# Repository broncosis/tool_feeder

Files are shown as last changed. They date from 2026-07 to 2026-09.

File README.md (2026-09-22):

# Tool Feeder

> **⚠ Experimental.** Under active development and tested on a limited set of
> hardware. Expect rough edges. Review generated configs before use and keep
> an eye on your printer — use at your own risk.

Filament management for Klipper toolchangers — automated per-tool loading,
live filament-lane status on the touchscreen, and Spoolman integration. Pick
any combination of:

- **Filament Feeder** — automated per-tool filament loading (macros + a buffer
  sync module supporting both one- and two-sensor hardware)
- **Spoolman Lane Sync** — background service that syncs Spoolman spool data into
  Moonraker's `lane_data` so OrcaSlicer sees what's loaded in each tool slot
- **KlipperScreen Filament Lanes** — a touchscreen panel showing live filament-lane
  status per tool

Each component installs independently.

## Screenshots

| Filament Lanes | Tool Map |
| --- | --- |
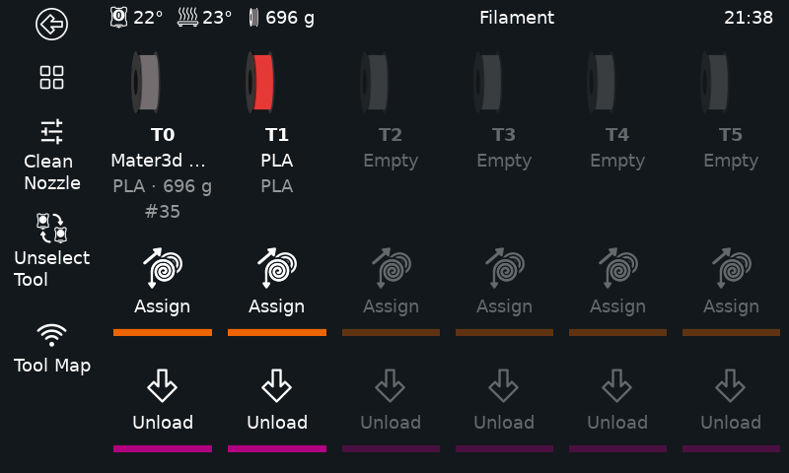
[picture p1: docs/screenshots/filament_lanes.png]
Filament Lanes
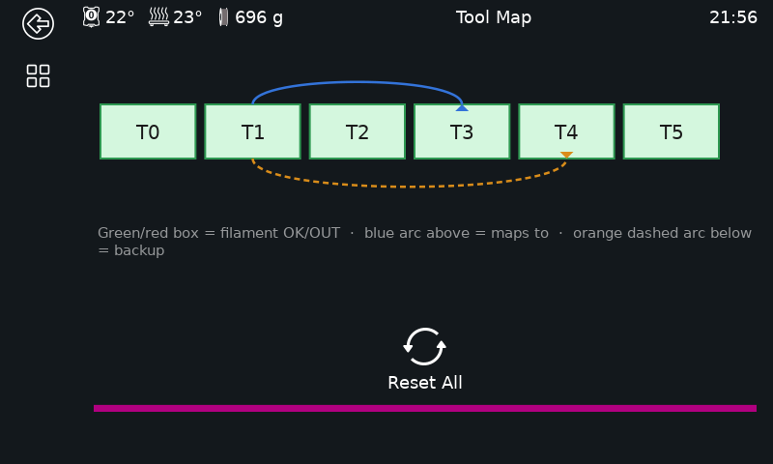
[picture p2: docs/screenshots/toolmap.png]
Tool Map
|  |  |
| Live per-lane status, right from the sidebar | Every tool's mapping at a glance |

| Manual Assign | Spoolman Assign |
| --- | --- |
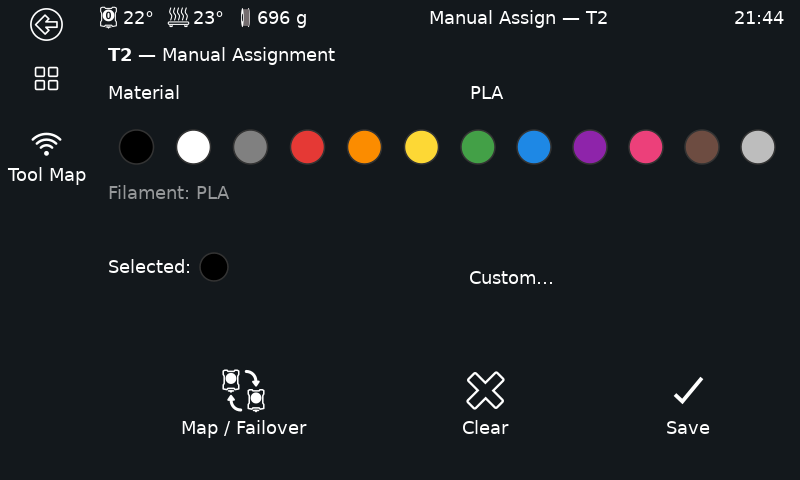
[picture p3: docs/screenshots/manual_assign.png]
Manual Assign
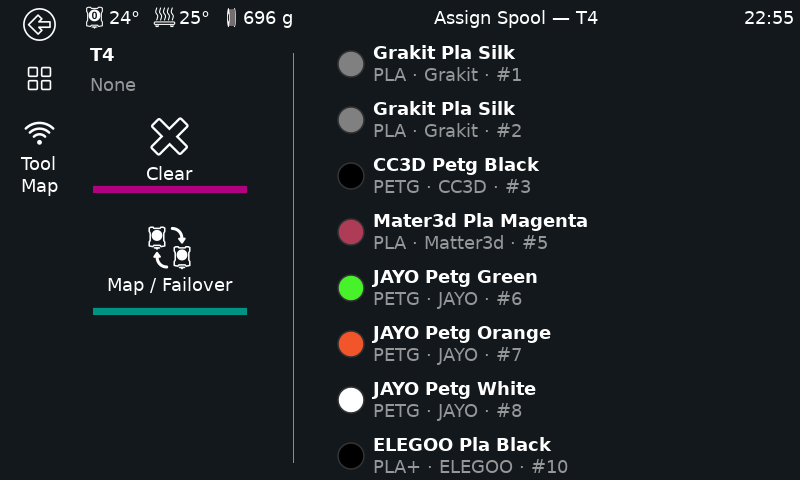
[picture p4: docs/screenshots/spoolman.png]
Spoolman Assign
|  |  |
| Color/material assignment without Spoolman | Pick a spool straight from Spoolman |

| Tool Routing |
| --- |
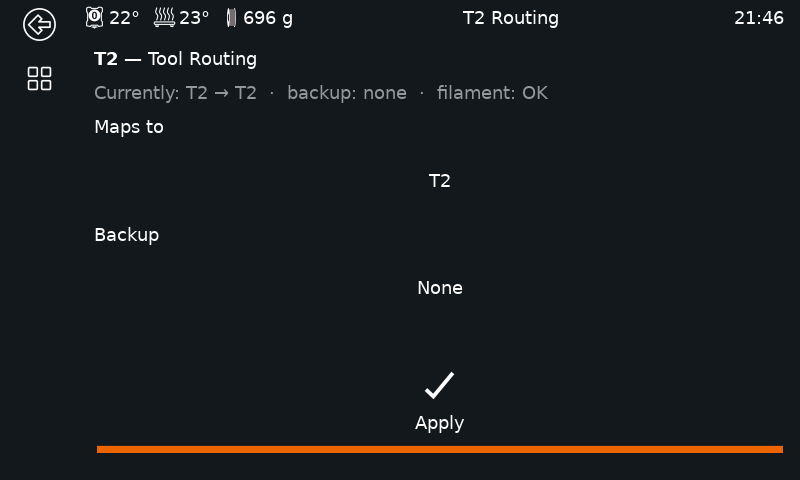
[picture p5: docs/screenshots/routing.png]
Tool Routing
|  |
| Per-lane remap/failover target |

---

## Requirements

- Klipper installed (for Filament Feeder)
- Moonraker + Spoolman installed (for Spoolman Lane Sync and richer KlipperScreen data)
- KlipperScreen installed (for the KlipperScreen panel)

None of these are required unless you install the component that needs them —
you'll get a clear message if a prerequisite is missing.

## Install

Run this one-liner on your printer's SSH session — no cloning required:

```bash
bash <(curl -fsSL https://raw.githubusercontent.com/broncosis/Tool_feeder/main/install.sh)
```

Or clone and run locally:

```bash
git clone https://github.com/broncosis/Tool_feeder.git
cd Tool_feeder
./install.sh
```

The installer detects your Klipper and config directories, lets you pick which
components to install, and — for Filament Feeder — asks about your setup:

- Whether you run Spoolman
- Number of tools — auto-detected from Klipper when possible, otherwise asked
  with a sensible default
- Load/unload temperature
- Whether you have physical unload buttons at the feeder (default yes — say
  no if you'd rather trigger unloads from the KlipperScreen panel or your own
  macro instead)
- Feeder MCU — picked from detected `/dev/serial/by-id/*` devices

From your answers it **generates** `feeder.cfg` (in your config directory
root) and one `T0.cfg`..`T{n-1}.cfg` per tool (in `toolchanger/tools/`,
matching klipper-toolchanger's own example layout), instead of shipping
static examples you'd otherwise hand-copy per tool. A couple of things
default to reasonable values instead of being asked outright — edit them
afterward if yours differ: purge bucket position (`bucket_x=25`,
`bucket_y=-4`) and Bowden tube length (1400mm).

The buffer sync module defaults to two-sensor mode (adds jam detection). If
your hardware only has one sensor, each tool's generated config already
includes a ready single-sensor block, commented out — just swap which one's
commented to switch.

What the installer *can't* know — per-tool pin wiring, TMC UART pins, CAN bus
UUIDs, dock park position, input shaper tuning — comes out as clearly marked
`CHANGE_ME_*` placeholders. Find them all with:

```bash
grep -rn CHANGE_ME_ ~/printer_data/config/feeder.cfg ~/printer_data/config/toolchanger/tools/T*.cfg
```

Re-running the installer never silently overwrites `feeder.cfg` or a `T{n}.cfg`
you already have — it backs the old one up first (`feeder.cfg.bak.<timestamp>`,
next to the original), then offers to carry over any real values you already
filled in (pins, `canbus_uuid`, dock position, etc.) into the newly generated
file, so re-running to change one setting doesn't mean re-entering everything
else from scratch.

For KlipperScreen: if Spoolman isn't installed, the panel's "Assign" button
goes straight to a manual color/material picker instead of a Spoolman browser
— pick a color from a preset swatch grid (or a custom color picker) and a
material from a tap-to-select list backed by `src/printer/materials.cfg` (edit
that file to add more materials). If Spoolman *is* installed, "Assign" offers a
choice between the two, per lane.

Every lane also has a **Map / Failover** page for tool remapping (e.g. route
T1 to T3 if T1 runs out) and backup-tool assignment, plus a **Tool Map**
overview reachable from the sidebar of any Filament screen, showing every
tool's current mapping and backup at a glance. The Filament panel is added to
both of KlipperScreen's menus — the idle main menu and the printing-status
page's own menu — so remapping/failover stays reachable mid-print, not just
when idle.

The installer also offers to add a single `[update_manager tool_feeder]` entry
to `moonraker.conf` covering whichever components you installed, so a `git
pull` on this repo updates all of them together. Spoolman Lane Sync gets
registered in `moonraker.asvc` so Moonraker is allowed to manage its service.

## Calibrating the Feeders

Each tool's feeder stepper has its own `rotation_distance` in `feeder.cfg`
(`[extruder_stepper _tool{n}_feeder]`) — how far it actually pushes filament
per motor rotation. If it's off, the buffer sync fights a constant bias
instead of correcting for real slack: `feeder_buffer`'s live `debug_console`
output (see below) can end up pinned on one state the entire print instead
of oscillating, because it's compensating for a miscalibrated base rate
rather than genuine feed/draw drift.

To calibrate tool `N`'s feeder independently of the toolhead extruder it's
synced to:

1. Make sure `[force_move] enable_force_move: True` is set somewhere in your
   config (required for the command below — Klipper won't run it otherwise).
2. Mark the filament with a pen right where it enters the feeder body (not
   at the hotend — you're measuring the feeder's own output).
3. Run a slow, known-distance test move on just that feeder stepper:

   ```
   FORCE_MOVE STEPPER="extruder_stepper _tool{N}_feeder" DISTANCE=100 VELOCITY=5
   ```

   The quotes around `STEPPER=` are required — the value contains a space,
   and Klipper's gcode parser splits on whitespace otherwise.
4. Measure how far the mark actually moved past your reference point.
5. Recalculate: `new_rotation_distance = old_rotation_distance * (measured_mm / 100)`.
6. Update `rotation_distance` for that tool in `feeder.cfg` and `RESTART`
   (a plain config edit doesn't take effect until Klipper reloads — or test
   live first with `SET_EXTRUDER_ROTATION_DISTANCE EXTRUDER=_tool{N}_feeder
   DISTANCE=<value>`, which applies immediately without a restart).

Repeat the measurement afterward to confirm it lands close to 100mm.

## Debugging a Buffer

`feeder_buffer`'s `debug_console` option (default `True`, see
`src/printer/feeder_buffer_spec.md`) prints every state change
(`Buffer T0: neutral -> advancing`, etc.) to the console, so you can confirm
a buffer is actually reacting to filament movement rather than just trusting
it silently. If it's pinned on one state indefinitely:

- Check with the printer idle first — if it's already pinned with no
  filament moving at all, that's a mechanical issue (spring tension, switch
  position), not a feed-rate one.
- If it only pins during printing, recalibrate that tool's `rotation_distance`
  (above) before assuming a sensor/wiring problem.
- If it's pinned on the *same* state no matter what you change the base
  calibration to — including deliberately making the mismatch worse — check
  `invert_sensor` (single-sensor mode only). If the sensor's active/inactive
  reading is backwards from what the code expects, the correction reinforces
  the drift instead of fixing it, so it never crosses back to the other
  state. Toggling `invert_sensor: True`/`False` for that tool flips which
  state gets the speed-up vs. slow-down correction.

Set `debug_console: False` per-tool once you've confirmed it's behaving, to
keep the console quiet during real prints.

## Credits

See [CREDITS.md](CREDITS.md) for full attribution.

## License

GPL v3 — see [LICENSE](LICENSE).

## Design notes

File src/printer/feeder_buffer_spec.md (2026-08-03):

# feeder_buffer.py — Design Specification

## Overview

A standalone Klipper extra that adapts the Belay single-sensor sync logic for a two-sensor buffer design. Intended as a drop-in replacement for Belay + BTT Smart Filament Sensor jam detection, with a clean migration path to AFC if the user later adopts it.

---

## Goals

- Replace Belay (secondary extruder sync) per tool
- Replace BTT Smart Filament Sensor jam detection per tool
- No AFC dependency
- Clean, complete removal path if migrating to AFC
- AFC config parameter names used throughout for migration compatibility
- Support arbitrary number of named instances (N tools, no hardcoded limit)

---

## Non-Goals

- Runout detection (handled externally — toolhead sensor or rewinder switch)
- Any modification to load/unload macros
- Multi-file architecture — single `.py` file only
- Any external dependencies beyond standard Klipper internals

---

## Hardware Context

- Printer: Bobby (5 tools), Ricky (6 tools, future)
- Secondary extruders are `extruder_stepper` objects (e.g. `_tool0_feeder`), not named extruders
- All feeder steppers on a shared `feeder` MCU
- The dual-sensor mode has two sensors: `advance` (buffer expanded) and `trailing` (buffer compressed)

---

## File Structure

```
klippy/extras/feeder_buffer.py   # single file, drop into extras/
```

No installer, no other files required.

---

## Config Section

Section name: `[feeder_buffer <name>]`

Each instance picks its sensor topology via `sensor_mode` (optional, default
`dual`). This lets one printer.cfg mix two-sensor tools and
Belay-compatible single-sensor tools under the same module, on the same
branch.

### `sensor_mode: dual` (default) — two-sensor buffer

```ini
[feeder_buffer T0]
sensor_mode: dual               # optional — this is the default
advance_pin: ^PA1               # required — AFC name match
trailing_pin: ^PA2              # required — AFC name match
extruder_stepper: _tool0_feeder # required — not in AFC (AFC manages this itself)
multiplier_high: 1.05           # optional, default 1.05 — AFC name + default match
multiplier_low: 0.95            # optional, default 0.95 — AFC name + default match
filament_error_sensitivity: 5   # optional, default 0 (disabled) — AFC name match
                                # 0 = disabled, 1 = least sensitive, 10 = most sensitive
                                # formula: fault_distance = (11 - sensitivity) * 10 mm
debug_console: True            # optional, default True — prints state transitions to
                                # the console (see "Debug Console Output" below)
```

### `sensor_mode: single` — Belay-compatible single-sensor buffer

Sensor-compatible with the Annex-Engineering Belay hardware design (see
CREDITS.md) — one switch, no neutral dead zone, **no jam detection**
(a single switch can't tell "stuck expanded" from "stuck compressed", and
Belay itself doesn't attempt jam detection either). `filament_error_sensitivity`
is not a valid option in this mode — Klipper's config validation will error at
startup if it's left in a single-mode section by mistake.

```ini
[feeder_buffer T5]
sensor_mode: single             # required — selects the single-sensor class
sensor_pin: ^PC3                # required
invert_sensor: False            # optional, default False — flip active-state
                                 # if wiring/logic reads backwards
extruder_stepper: _tool5_feeder # required
multiplier_high: 1.05           # optional, default 1.05 — matches Belay's default
multiplier_low: 0.95            # optional, default 0.95 — matches Belay's default
debug_console: True             # optional, default True — see "Debug Console Output" below
```

---

## Sensor Logic / State Machine

Three states per instance:

| State | Condition | Action |
|---|---|---|
| `advancing`| trailing pin triggered | apply `multiplier_low` to rotation_distance  |
| `trailing` | advance pin triggered | apply `multiplier_high` to rotation_distance |
| `neutral`  | neither pin triggered | no rotation_distance change |

- `multiplier_high` increases rotation_distance → slows secondary extruder → buffer compresses
- `multiplier_low` decreases rotation_distance → speeds secondary extruder → buffer expands
- Neutral zone provides hysteresis — no hunting

State mirrors AFC `AFC_buffer` logic exactly so behaviour is consistent pre/post migration.

---

## Debug Console Output

`debug_console` (default `True`, per-instance) makes every state transition
print to the console via `gcode.respond_info`, e.g.:

```
Buffer T0: neutral -> advancing
Buffer T0: advancing -> neutral
```

Only fires on an actual state change (not on every sensor poll), so it's
useful for confirming the sensors are wired correctly and triggering as
filament moves, without flooding the console. Set to `False` per-tool once
you've verified a buffer is working, to keep the console quiet during real
prints.

---

## Jam Detection

Uses `filament_error_sensitivity` to derive a `fault_distance` in mm:

```
fault_distance = (11 - sensitivity) * 10
```

- Monitors extruder position
- If extruder travels `fault_distance` mm without a buffer state change, jam is triggered
- Sensitivity 0 disables fault detection entirely
- On trigger: calls `FEEDER_BUFFER_JAM` macro with `TOOL=<name>` and `SENSOR=<advance|trailing>`
  - `advance` stuck triggered → buffer expanding but not compressing → downstream clog
  - `trailing` stuck triggered → buffer compressing but not expanding → upstream feed problem

---

## Jam Macro

A default macro ships with the module as a GCode macro in the `.py` file:

```ini
[gcode_macro FEEDER_BUFFER_JAM]
description: Called when a jam is detected by feeder_buffer. Override to customise behaviour.
gcode:
    {action_respond_info("Jam detected on %s (sensor: %s)" % (params.TOOL, params.SENSOR))}
    PAUSE
```

User can override by redefining `[gcode_macro FEEDER_BUFFER_JAM]` in their own config. The module always calls the macro by name, so the override takes effect transparently.

---

## GCode Commands

Mirror AFC buffer commands exactly:

| Command | Parameters | Description |
|---|---|---|
| `QUERY_BUFFER` | `BUFFER=<name>` | Reports current state and rotation_distance of named instance |
| `SET_ROTATION_FACTOR` | `BUFFER=<name> FACTOR=<float>` | Directly applies a rotation factor to the extruder_stepper |
| `SET_BUFFER_MULTIPLIER` | `BUFFER=<name> MULTIPLIER=<HIGH\|LOW> FACTOR=<float>` | Live-adjusts multiplier_high or multiplier_low |

---

## Belay Migration Notes

For a tool currently running the actual Belay module, switching to
`feeder_buffer.py` with `sensor_mode: single` means:

- Same physical sensor, same wiring — just point `sensor_pin` at whatever
  pin the Belay config used for its switch.
- `multiplier_high`/`multiplier_low` carry across unchanged (same names,
  same defaults).
- Jam detection is not gained or lost — Belay never had it.
- Remove the `[belay]` (or equivalent) section and the Belay module install;
  add `[feeder_buffer <name>]` with `sensor_mode: single` instead.

This lets every tool across every printer install from the same
`feeder_buffer.py` file/branch, regardless of which sensor hardware
that tool has.

---

## Removal / AFC Migration Instructions

**To remove the module:**
1. Delete `feeder_buffer.py` from `klippy/extras/`
2. Remove all `[feeder_buffer <name>]` sections from config
3. Remove `[gcode_macro FEEDER_BUFFER_JAM]` if defined
4. Restart Klipper

Nothing else is modified by this module — no side effects to clean up.

**To migrate to AFC:**
1. Install AFC per its documentation
2. For each `[feeder_buffer <name>]` section:
   - Change section header to `[AFC_buffer <name>]`
   - Remove the `extruder_stepper` line (AFC manages stepper assignment itself)
   - All other parameters (`advance_pin`, `trailing_pin`, `multiplier_high`, `multiplier_low`, `filament_error_sensitivity`) copy across unchanged
3. Remove `feeder_buffer.py` and `[gcode_macro FEEDER_BUFFER_JAM]`
4. Follow AFC documentation for buffer assignment to lanes/steppers

---

## Example Full Config (Bobby, 5 tools)

```ini
[feeder_buffer T0]
advance_pin: ^feeder:PA1
trailing_pin: ^feeder:PA2
extruder_stepper: _tool0_feeder
multiplier_high: 1.05
multiplier_low: 0.95
filament_error_sensitivity: 5

[feeder_buffer T1]
advance_pin: ^feeder:PA3
trailing_pin: ^feeder:PA4
extruder_stepper: _tool1_feeder
multiplier_high: 1.05
multiplier_low: 0.95
filament_error_sensitivity: 5

[feeder_buffer T2]
advance_pin: ^feeder:PB1
trailing_pin: ^feeder:PB2
extruder_stepper: _tool2_feeder
multiplier_high: 1.05
multiplier_low: 0.95
filament_error_sensitivity: 5

[feeder_buffer T3]
advance_pin: ^feeder:PB3
trailing_pin: ^feeder:PB4
extruder_stepper: _tool3_feeder
multiplier_high: 1.05
multiplier_low: 0.95
filament_error_sensitivity: 5

[feeder_buffer T4]
advance_pin: ^feeder:PC1
trailing_pin: ^feeder:PC2
extruder_stepper: _tool4_feeder
multiplier_high: 1.05
multiplier_low: 0.95
filament_error_sensitivity: 5

[gcode_macro FEEDER_BUFFER_JAM]
description: Override this macro to customise jam response per printer
gcode:
    {action_respond_info("Jam detected on %s (sensor: %s)" % (params.TOOL, params.SENSOR))}
    PAUSE
```

---

## Key Implementation Notes for Coding

- Use `printer.lookup_object('extruder_stepper <name>')` to get stepper reference
- Modify `rotation_distance` via the stepper's `stepper` attribute at runtime
- Register buttons via `printer.lookup_object('buttons')` using `register_button`
- Jam detection timer via `reactor.register_timer`
- Each instance is fully independent — separate class, separate state, separate timer
- `load_config_prefix` used to support named instances
- Default macro registered via `printer.load_config` pattern or included as a separate `[gcode_macro]` block in a bundled `.cfg` file — TBD based on cleanest Klipper pattern

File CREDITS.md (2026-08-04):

# Credits

## Component origins (Broncosis)

- **Filament_feeder** — https://github.com/broncosis/Filament_feeder — License: GPL v3 (confirmed — see the `dev_router` branch's `LICENSE` file)
- **spoolman-lane-sync** — https://github.com/broncosis/spoolman-lane-sync — License: MIT (confirmed)
- **KlipperScreen-filament-lanes** — https://github.com/broncosis/KlipperScreen-filament-lanes — License: GPL v3 (confirmed)

## Third-party inspiration and hardware compatibility

### Annex Engineering — Belay
- **Source:** https://github.com/Annex-Engineering/Belay
- **License:** CC BY-NC-SA 4.0 (verified directly from the repo's `LICENSE.md` — this is *more restrictive* than GPL v3 due to the NonCommercial clause)
- **Used for:** Hardware/sensor-compatibility reference only. Tool Feeder's own `feeder_buffer.py` includes a `sensor_mode: single` mode that's wiring-compatible with Belay's single-sensor hardware, for users who already have that sensor installed — but it's an independent implementation. No Belay code is installed, cloned, or redistributed by Tool Feeder anywhere.

### Armoured Turtle / AFC
- **Source:** https://github.com/AFCProject/AFC-Klipper-Add-On, https://github.com/ArmoredTurtle/AFC-Klipper-Screen-Add-On
- **License:** GPL v3 (confirmed)
- **Used for:** Two-sensor buffer concept and hardware that `feeder_buffer.py` is designed to work with. The two-sensor approach and AFC's config-parameter naming convention are used as inspiration, not copied code.

### CapTightpants — SIFM (Spoolman Interactive Filament Manager)
- **Source:** https://github.com/CapTightpants/SIFM
- **License:** Unknown — used with explicit permission from the author
- **Used for:** The tip-forming wiggle sequence in `UNLOAD_ANY_TOOL` is based on `_SIFM_LOAD_FINISH` from SIFM.

### N3MI-DG — Prime Lines Macro
- **Source:** No public repo/link — direct community sharing
- **License:** Unknown — used with explicit permission from the author
- **Used for:** `prime_purge.cfg`'s `PRIME_PURGE` macro (per-tool prime/purge
  sequence run at print start) started from N3MI-DG's prime lines macro,
  since heavily modified — only loosely based on the original at this point.

### Nic335 — Tool Router
- **Source:** https://github.com/nic335
- **License:** Unknown — used with explicit permission from the author
- **Used for:** Tool remapping and spool-failover logic (`toolmap.cfg`: `_TOOLMAP`, `_TOOL_ROUTER`, `SET_TOOLMAP`, `SET_TOOL_FILAMENT_STATUS`, `RESET_TOOLMAP`, `SHOW_TOOLMAP`).

### KlipperScreen
- **Source:** https://github.com/KlipperScreen/KlipperScreen
- **License:** GPL v3
- **Used for:** The spool-icon SVG color-substitution pattern in `panels/filament_lanes.py` is adapted from KlipperScreen's own `panels/spoolman.py`. The `ScreenPanel` base class and GTK helper infrastructure (`_gtk`, `_screen`, `_printer`) are part of KlipperScreen.

### Klipper / Moonraker
- **Source:** https://github.com/Klipper3d/klipper, https://github.com/Arksine/moonraker
- **License:** GPL v3
- **Used for:** The `save_variables` persistence mechanism, Moonraker's database namespace API (`lane_data`), Spoolman proxy API, and `update_manager`/systemd service conventions.

### Spoolman
- **Source:** https://github.com/Donkie/Spoolman
- **License:** MIT
- **Used for:** Spool/filament/material data model and the `Location` field convention (`T0`, `T1`, ... → tool slot).

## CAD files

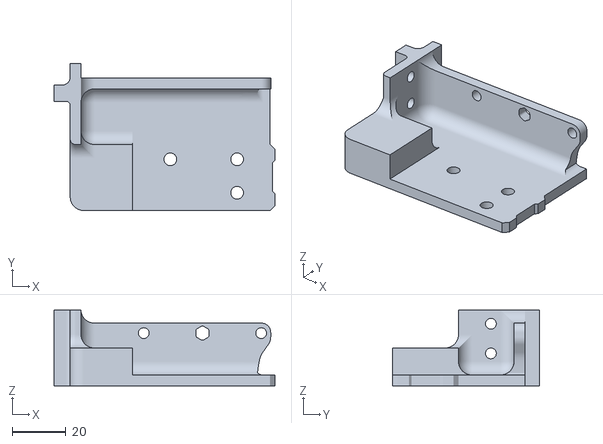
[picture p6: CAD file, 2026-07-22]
hardware/sherpamount.stl
81.9 x 54.5 x 28.0

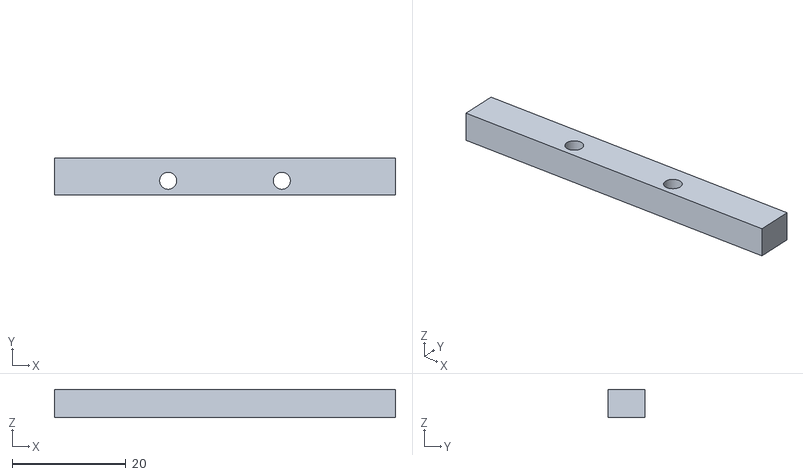
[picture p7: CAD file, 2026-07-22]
hardware/side_panel_spacer.stl
60.0 x 6.50 x 5.00

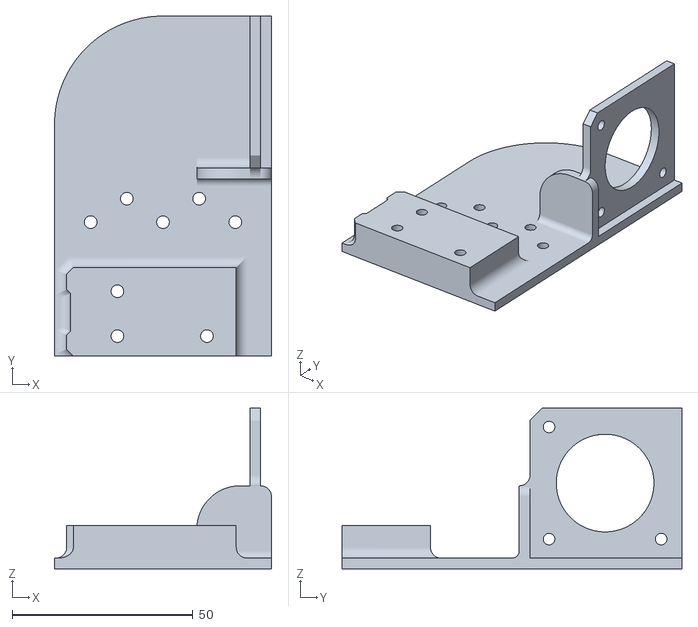
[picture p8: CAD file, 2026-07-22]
hardware/bmg_sfs2mount.stl
60.0 x 94.0 x 44.5

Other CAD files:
hardware/bmg_sfs2mount_with_button.stl

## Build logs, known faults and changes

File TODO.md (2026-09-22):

# Tool Feeder — To-Do

Living backlog of features and bugs in this repo's own code/config/docs.
Machine-specific deployment/hardware status (which printer has which fix,
physical checks needed, etc.) belongs in `.claude/CONTEXT.md`'s running log
instead, not here. Link to a GitHub issue (`#N`) instead of writing detail
here once one exists.

## Features

- [ ] Add linting to the codebase, similar to what Spoolman does, to make
      the code more readable and manageable. Spoolman uses **Ruff only**
      (linter + formatter, no Black/mypy/isort/Flake8) via `[tool.ruff]` in
      `pyproject.toml`: `line-length = 120`, `target-version = "py310"`,
      `[tool.ruff.lint] select = ["ALL"]` with a curated ignore list, plus
      `[tool.ruff.lint.per-file-ignores]` relaxing rules for
      tests/migrations/scripts. For Tool_feeder: add a `pyproject.toml`
      covering `src/screen/` and `src/sync/`, pick a starting ignore list
      (KlipperScreen's `Panel` subclassing and Klipper macro conventions may
      need their own per-file relaxations), and decide whether to enforce it
      in CI or just document `ruff check`/`ruff format` as a dev step.
- [ ] Possibly bring tool mapping and load/unload controls to Fluidd/Mainsail
      too, not just KlipperScreen — currently `SET_TOOLMAP`/load/unload are
      only reachable via KlipperScreen panels or the console. Exploratory —
      not scoped yet (macro-based UI panel? plugin? just documented console
      macros for now?).

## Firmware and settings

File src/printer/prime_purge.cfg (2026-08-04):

# prime_purge.cfg
# Per-tool prime/purge sequence run at print start: primes every tool that
# will be used in the print (passed as T0_TEMP, T1_TEMP, ... params), keeping
# the initial print tool hot last so it's ready to print immediately.
#
# Based on work by N3MI-DG (no public repo/link - shared directly)
# Original license: Unknown - used with explicit permission from the author
# Heavily modified since - only loosely based on the original at this point.
#
# Install: [include prime_purge.cfg], call from your slicer's start gcode
# (or your own print-start macro) as e.g.:
#   PRIME_PURGE INITIAL_TOOL={initial_tool} T0_TEMP=210 T1_TEMP=0 ...
#
# Requires: klipper-toolchanger (printer.toolchanger, SELECT_TOOL - not part
# of Tool Feeder), CLEAN_NOZZLE and the T<n> macros / SET_FILAMENT_SENSOR
# encoder_sensor_T<n> objects from this repo's tool_feeder_macros.cfg /
# tool.cfg.template.

[gcode_macro PRIME_PURGE]
description: Prime all extruders before printing.
  INITIAL_TOOL= Tool number, optional.
variable_purge_volume:         40      # Amount to purge
variable_initial_tool_retract: 0.5    # Retraction distance for the initial tool (if defined) after prime
variable_docked_tool_retract:  5      # Retraction distance for docked tools after prime
variable_z_move_pos:           5      # Distance from bed on Z axis while moving
variable_move_speed:           10000  # Travel move speed
variable_prime_speed:          200    # Prime speed
variable_temp_drop:            50     # 90Amount of temperature drop applied to nozzles that are being docked
variable_purge_x:              5     # X purge location
variable_purge_y:              0   # y Pruge location
variable_retract_speed:        1000   # retract speed
gcode:
  SAVE_GCODE_STATE NAME=PRIME_PURGE_STATE

  # Disable encoder sensors during purge to prevent false runouts
  {% for tn in printer.toolchanger.tool_numbers %}
    SET_FILAMENT_SENSOR SENSOR=encoder_sensor_T{tn} ENABLE=0
  {% endfor %}

  # Build active tool list from passed T0_TEMP, T1_TEMP etc params
  {% set print_tools = [] %}
  {% for tn in printer.toolchanger.tool_numbers %}
    {% set tooltemp_param = 'T' ~ tn|string ~ '_TEMP' %}
    {% if tooltemp_param in params and params[tooltemp_param]|int > 0 %}
      {% set _ = print_tools.append(tn) %}
    {% endif %}
  {% endfor %}

  # Re-order: initial_tool purged last so it stays hot for printing
  {% if params.INITIAL_TOOL is defined %}
    {% set initial_tool = params.INITIAL_TOOL|int %}

    {% if print_tools|length > 1 %}
      {% set snorlax = print_tools.pop(print_tools.index(initial_tool)) %}
      {% set _ = print_tools.append(initial_tool) %}
    {% endif %}

    {% if printer.toolchanger.tool_number != initial_tool
        and printer.toolchanger.tool_number != print_tools[0]
        and printer.toolchanger.tool_number in print_tools %}
      {% set mimikyu  = print_tools.pop(print_tools.index(printer.toolchanger.tool_number)) %}
      {% set bulbasaur = print_tools.insert(0, printer.toolchanger.tool_number) %}
    {% endif %}

  {% else %}
    {% set initial_tool = None %}
  {% endif %}

  {% for tn in print_tools %}
    T{tn}
    # No explicit T=/HEATER= targeting below - M104/M109 with no T parameter
    # always heat whatever extruder is *currently active* (confirmed in
    # Klipper's own kinematics/extruder.py cmd_M104: an explicit T= does a
    # literal "extruder"/"extruderN" lookup with no toolchanger awareness,
    # but omitting T= uses toolhead.get_extruder(), i.e. whatever T{tn} just
    # made active). That's correct regardless of whether T{tn} was remapped
    # by SET_TOOLMAP, redirected to a backup tool, or ran as a plain
    # identity selection - no need to track/recompute which physical tool
    # ended up active.
    {% set tooltemp_param = 'T' ~ tn|string ~ '_TEMP' %}
    {% set heat_temp = params[tooltemp_param]|int %}

    G0 X{purge_x} Y{purge_y} Z{z_move_pos} F{move_speed}

    M109 S{heat_temp}

    RESPOND TYPE=echo MSG="Priming T{tn} ({printer.toolhead.extruder}) at {heat_temp}C"
    M83
    G92 E0
    G91
    G1 E{purge_volume} F{prime_speed}
    G1 E-{initial_tool_retract if tn == initial_tool else docked_tool_retract} F{retract_speed}
    G4 P2000
    CLEAN_NOZZLE

    {% if initial_tool is not none and initial_tool in print_tools and tn != initial_tool %}
      M104 S{heat_temp - temp_drop}
    {% endif %}

    G90
  {% endfor %}

  # Re-enable encoder sensors after purge
  {% for tn in printer.toolchanger.tool_numbers %}
    SET_FILAMENT_SENSOR SENSOR=encoder_sensor_T{tn} ENABLE=1
  {% endfor %}

  RESTORE_GCODE_STATE NAME=PRIME_PURGE_STATE

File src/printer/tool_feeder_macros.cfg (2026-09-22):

# =============================================================================
# macros.cfg — all Filament Feeder macro logic (load/unload, tool routing,
# spool-assignment restore, nozzle cleaning). No hardware or per-printer
# tuning values live here — that's all in feeder.cfg's _FEEDER_VARS block.
# Merged from feeder_macros.cfg + toolmap.cfg + spool_sync.cfg + clean_nozzle.cfg
# — each section below keeps its own attribution comment where it already was.
# =============================================================================

# =============================================================================
# feeder_macros.cfg — load/unload macro logic (Bowden feeder)
# =============================================================================
# This file contains only macro logic — no MCU, pin, or hardware settings,
# and no per-printer tuning values. That all lives in feeder.cfg's
# [gcode_macro _FEEDER_VARS] block instead.
#
# Keeping this split means this file can be safely replaced/updated (e.g. via
# a future Moonraker update_manager entry) without ever touching your bucket
# position, temps, or other tuned settings in feeder.cfg.
#
# Requires feeder.cfg to be included too (MCU, steppers, and _FEEDER_VARS).
# =============================================================================


# -----------------------------------------------------------------------------
# Safety guard — called at the start of every load/unload macro
# Raises an error (halts execution) if any condition is not met
# -----------------------------------------------------------------------------

[gcode_macro _CHECK_READY]
description: Abort if machine is not homed, QGL not applied, or actively printing
gcode:
    {% if printer.toolhead.homed_axes != "xyz" %}
        { action_raise_error("Machine not homed.") }
    {% elif printer.quad_gantry_level.applied|lower == 'false' %}
        { action_raise_error("QGL not applied.") }
    {% elif printer.print_stats.state == "printing" and not printer.pause_resume.is_paused %}
        { action_raise_error("Print is active. Pause or cancel before loading/unloading.") }
    {% endif %}


# -----------------------------------------------------------------------------
# LOAD_ANY_TOOL — sensor-based load
# Positions toolhead at purge bucket then calls _FILAMENT_FEED. Heating and
# purging happen in _LOAD_COMPLETE once the toolhead sensor triggers.
#
# Parameters:
#   T = tool index
#   S = feeder speed in mm/s (default 30)
#   D = max feed distance / bowden length in mm (default 1400)
# -----------------------------------------------------------------------------

[gcode_macro LOAD_ANY_TOOL]
description: [T<index>] [S<speed>] [D<distance>] Load filament using sensor feedback
variable_paused: 0  # tracks pause state for _LOAD_COMPLETE
gcode:
    _CHECK_READY
    {% set fv = printer["gcode_macro _FEEDER_VARS"] %}
    {% set T = params.T|int %}
    {% set speed = params.S|default(30)|float %}
    {% set max_dist = params.D|default(1400)|float %}
    {% set paused = printer.pause_resume.is_paused %}

    {% if printer.toolchanger.tool_number|int != T %}
        RESPOND MSG="Switching to tool {T}"
        T{T}
    {% endif %}

    SET_GCODE_VARIABLE MACRO=LOAD_ANY_TOOL VARIABLE=paused VALUE={1 if paused else 0}

    G90
    {% if not paused %}
        {% if printer.toolhead.position.z < 20 %}
            G1 Z20 F900
        {% endif %}
        G1 X{fv.bucket_x} Y{fv.bucket_y} F1800
    {% else %}
        M118 Print is paused: skipping move to purge bucket
    {% endif %}

    M104 S{fv.load_temp}
    _FILAMENT_FEED T={T} S={speed} MAX={max_dist} D={fv.feed_step}


# -----------------------------------------------------------------------------
# _LOAD_COMPLETE — called by _FILAMENT_FEED_LOOP when sensor triggers
# Heats, purges, and cleans up. Reads context from _FEEDER_VARS / LOAD_ANY_TOOL.
# -----------------------------------------------------------------------------

[gcode_macro _LOAD_COMPLETE]
gcode:
    {% set fv = printer["gcode_macro _FEEDER_VARS"] %}
    {% set T = printer["gcode_macro _FILAMENT_FEED"].tool|int %}
    {% set paused = printer["gcode_macro LOAD_ANY_TOOL"].paused|int %}

    M109 S{fv.load_temp}
    M83
    G1 E{fv.load_purge} F300
    G1 E-5 F1800
    M82
    M400

    {% if not paused %}
        CLEAN_NOZZLE
        M104 S0
    {% endif %}

    M118 Tool {T} loaded


# -----------------------------------------------------------------------------
# _FILAMENT_FEED — entry point for sensor-based feeding
#
# Does a fast blind pre-feed (preload mm) to cover most of the bowden quickly,
# then hands off to _FILAMENT_FEED_LOOP which steps and checks the toolhead
# sensor each iteration.
#
# Parameters:
#   T       = tool index (default 0)
#   S       = feed speed in mm/s (default 30)
#   D       = step size for the sensor loop in mm (default 10)
#   MAX     = maximum total distance before aborting (default 1900)
#   PRELOAD = blind fast-feed distance before sensor loop starts (default 800)
# -----------------------------------------------------------------------------

[gcode_macro _FILAMENT_FEED]
variable_tool:      0
variable_speed:    30
variable_dist:     10
variable_max_dist: 1900
variable_preload:   800
variable_moved:     0
gcode:
    {% set T = params.T|default(0)|int %}
    {% set speed = params.S|default(speed)|float %}
    {% set dist = params.D|default(dist)|float %}
    {% set max_dist = params.MAX|default(max_dist)|float %}
    {% set preload = params.PRELOAD|default(preload)|float %}
    {% set sensor = "filament_switch_sensor filament_sensor_at_T%s" % T %}

    SET_GCODE_VARIABLE MACRO=_FILAMENT_FEED VARIABLE=tool VALUE={T}
    SET_GCODE_VARIABLE MACRO=_FILAMENT_FEED VARIABLE=speed VALUE={speed}
    SET_GCODE_VARIABLE MACRO=_FILAMENT_FEED VARIABLE=dist VALUE={dist}
    SET_GCODE_VARIABLE MACRO=_FILAMENT_FEED VARIABLE=max_dist VALUE={max_dist}
    SET_GCODE_VARIABLE MACRO=_FILAMENT_FEED VARIABLE=moved VALUE=0

    {% if printer[sensor].filament_detected %}
        RESPOND MSG="Tool {T}: Filament already at sensor — proceeding to heat and purge"
        _LOAD_COMPLETE
    {% else %}
        RESPOND MSG="Tool {T}: Starting filament feed"
        FORCE_MOVE STEPPER="extruder_stepper _tool{T}_feeder" DISTANCE={preload} VELOCITY={speed}
        SET_GCODE_VARIABLE MACRO=_FILAMENT_FEED VARIABLE=moved VALUE={preload}
        UPDATE_DELAYED_GCODE ID=_FILAMENT_FEED_LOOP DURATION=0.1
    {% endif %}


# -----------------------------------------------------------------------------
# _FILAMENT_FEED_LOOP — sensor-checking step loop (called via delayed_gcode)
#
# Reads state from _FILAMENT_FEED variables each iteration so sensor data is
# always fresh. Reschedules itself until sensor triggers or max distance hit.
# -----------------------------------------------------------------------------

[delayed_gcode _FILAMENT_FEED_LOOP]
gcode:
    {% set T = printer["gcode_macro _FILAMENT_FEED"].tool|int %}
    {% set speed = printer["gcode_macro _FILAMENT_FEED"].speed|float %}
    {% set dist = printer["gcode_macro _FILAMENT_FEED"].dist|float %}
    {% set max_dist = printer["gcode_macro _FILAMENT_FEED"].max_dist|float %}
    {% set moved = printer["gcode_macro _FILAMENT_FEED"].moved|float %}
    {% set sensor = "filament_switch_sensor filament_sensor_at_T%s" % T %}

    {% if printer[sensor].filament_detected %}
        RESPOND MSG="Tool {T}: Sensor triggered at {moved}mm"
        _LOAD_COMPLETE
    {% elif moved >= max_dist %}
        RESPOND MSG="Tool {T}: Max distance {max_dist}mm reached, aborting"
    {% else %}
        FORCE_MOVE STEPPER="extruder_stepper _tool{T}_feeder" DISTANCE={dist} VELOCITY={speed}
        SET_GCODE_VARIABLE MACRO=_FILAMENT_FEED VARIABLE=moved VALUE={moved + dist}
        UPDATE_DELAYED_GCODE ID=_FILAMENT_FEED_LOOP DURATION=0.1
    {% endif %}


# -----------------------------------------------------------------------------
# LOAD_ANY_TOOL_DIST — fixed-distance load (no sensor required)
# Use this for setups without a toolhead filament sensor.
# Measure your PTFE tube length carefully — filament will feed exactly D mm.
#
# Parameters:
#   T = tool index
#   S = feeder speed in mm/s (default 30)
#   D = distance to feed in mm (default 1400)
# -----------------------------------------------------------------------------
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

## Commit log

2026-07-22 Initial commit: unified Tool Feeder installer
    Combines three previously-separate Klipper toolchanger projects - Filament
    Feeder (macros + buffer sync), Spoolman Lane Sync (background service), and
    a KlipperScreen filament-lanes panel - into one repo with one installer.
    Installer templates feeder/tool configs from setup questions rather than
    handing over static example files to hand-edit.
    [bmg_sfs2mount.stl, bmg_sfs2mount_with_button.stl, feeder_buffer_example.cfg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]
2026-07-24 Fix real-hardware bugs: feeder_buffer sensor wiring, toolmap Jinja escaping, installer non-destructive overwrite, and KlipperScreen filament panel crashes
    Verified live against voron300 over SSH. feeder_buffer.py had a wrong
    extruder_stepper attribute chain and sensor registration deferred past
    Klipper's config-build phase; tool_feeder_macros.cfg's RESET_TOOLMAP had a
    bare {} literal misparsed by Klipper's Jinja scanner; install.sh now backs
    up and offers to merge forward existing CHANGE_ME_ values instead of
    clobbering them on re-run. KlipperScreen's filament_lanes*.py used an
    apiclient attribute and Panel.get_toplevel() that don't exist on this
    KlipperScreen version, and called the async s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
    [feeder_buffer_example.cfg, feeder_buffer_ricky.cfg, tool_feeder_macros.cfg]
2026-07-26 Add tool-mapping/failover KlipperScreen UI, fix touchscreen dropdowns, off-screen controls, and SAVE_VARIABLE gcode escaping
    Adds a per-lane routing panel (Maps to/Backup) and an all-tools diagram
    overview, both reachable from the Filament panel's Map/Failover flow.
    Gtk.ComboBoxText never stayed open on touch (its popup grab doesn't survive
    a touchscreen tap under KlipperScreen's window-manager-less Xorg), so
    material/target/backup pickers are now tap-to-open list dialogs via a new
    touch_picker.py. filament_lanes_manual.py's Name/Map-Failover/Clear/Save
    controls were unreachable, pushed off KlipperScreen's 480px screen with no
    scroll wrapper. Manual Assignment's Save always raised "Malforme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
    [tool_feeder_macros.cfg]
2026-07-27 Move Tool Map to a persistent sidebar button, fix diagram overflow and sidebar layout bugs
    Tool Map is now reachable from anywhere in the Filament section via a
    sidebar action_bar button, instead of a per-lane Routing-page button that
    turned out to be permanently unreachable (pushed off KlipperScreen's 480px
    screen with no scrolling, which the user explicitly doesn't want used as a
    fix here).
    Chased down several real layout bugs by reading KlipperScreen's own
    screen.py/base_panel.py/base.css rather than guessing:
    - show_panel() deactivates the previous top panel on every transition, not
    just "back" -- hiding the sidebar's notification/shutdown icons only
    worked reliably once every filam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
2026-07-28 Fix Tool Map overview never refetching, compress Manual Assign, share the sidebar button across all assign screens
    filament_lanes_toolmap.py only fetched _TOOLMAP state in __init__, but
    KlipperScreen's show_panel() only calls __init__ the first time a panel
    name is created -- every later visit reuses the cached instance via
    activate() alone, so the diagram was stuck showing whatever state existed
    the first time it was ever opened. Now refetches on every activate().
    Manual Assignment page compressed further to fit without scrolling:
    material label+picker on one row, all 12 color presets on a single row,
    Map/Failover+Clear+Save merged onto one row, Custom/Selected reordered and
    resized, a liv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
2026-07-30 Refresh docs/screenshots, add Tool Map button to Routing page, fix vexpand spacing bug
    - README: move screenshots to the top with captions, fix stale "dropdown"
    wording (material picker is now a tap-to-select list), document Map/Failover
    and Tool Map features that were never mentioned.
    - docs/screenshots/*.png: retaken live on voron300, replacing 3-day-stale
    captures that predated the sidebar declutter and Manual Assign compression.
    Added toolmap.png (previously undocumented).
    - filament_lanes_routing.py: add the shared Tool Map sidebar button, previously
    intentionally omitted pending confirmation - now requested.
    - Fixed a real layout bug found while screenshotting: KlipperScreen'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
2026-07-30 Add missing Spoolman Assign screenshot to README
    The screenshot grid covered Filament Lanes, Manual Assign, Tool Routing, and
    Tool Map but never the Spoolman spool browser - the fourth core panel.
    Reorganized the grid into three rows so Manual/Spoolman Assign sit side by
    side as the two branches of the same "Assign" flow.
2026-08-01 Fix invalid managed_services values in [update_manager tool_feeder]
    Moonraker warned: "Option 'managed_services: klipper spoolman-lane-sync
    KlipperScreen' contains an invalid value 'spoolman-lane-sync'. All values
    must be one of the following choices: ['tool_feeder', 'klipper', 'moonraker']"
    Root-caused by reading Moonraker's own update_manager/app_deploy.py: a
    git_repo entry's managed_services can only ever contain its own section
    name, "klipper", or "moonraker" - there's no way for one entry to declare
    an arbitrary third-party systemd service as managed. install.sh was listing
    spoolman-lane-sync and KlipperScreen there, which Moonraker always rejected.
    Fix: managed_services now only ever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
2026-08-03 Add debug_console option to feeder_buffer for live state-change visibility
    There was previously no way to tell a buffer was actually working short of
    running QUERY_BUFFER on demand - sensor state transitions happened silently.
    Adds a per-instance debug_console config option (default True) that prints
    "Buffer T0: neutral -> advancing" etc. to the console via gcode.respond_info
    whenever the state actually changes (not on every sensor poll, so it can't
    spam the console). Set to False per-tool once a buffer is confirmed working,
    to keep the console quiet during real prints.
    Refactored both DualSensorBuffer._update() and BelaySensorBuffer._update()
    to share a new _BufferBase._apply_state() help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
    [feeder_buffer_example.cfg]
2026-08-03 Fix feeder_buffer rotation_distance no-op bug, add calibration docs to README
    Real bug found while diagnosing why a buffer's live correction never
    affected actual feed rate: _set_rd() was setting `.rotation_dist` directly,
    an attribute that doesn't exist anywhere in Klipper's own stepper.py (a
    whole-tree grep confirms it - only this file ever referenced it). The real,
    motion-affecting state is private (_rotation_dist/_step_dist), only safely
    mutable via stepper.set_rotation_distance(), which also re-anchors MCU
    position tracking. Every prior "live" multiplier correction has been a
    silent no-op since this module was written - state tracking and console
    output were real, but the feeder's actua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
2026-08-04 Add prime_purge.cfg, fix its toolmap-remap heating bug
    Real bug found live on voron300: PRIME_PURGE's per-tool loop calls T{tn}
    (correctly resolves any SET_TOOLMAP remap or backup-tool fallback via
    _TOOL_ROUTER), but then computed which extruder to heat by reconstructing
    "extruder" + tn - the original, unmapped tool number - instead of whatever
    tool actually ended up selected. If T1 was remapped to T3, it would select
    tool 3 but heat extruder1.
    Fixed by dropping explicit T=/HEATER= targeting entirely: M104/M109 with no
    T parameter always heat whatever extruder is currently active (confirmed in
    Klipper's own kinematics/extruder.py cmd_M104 - an explicit T= does a
    literal "extruder"/"extruder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
    [prime_purge.cfg]
2026-08-04 Add reactive mid-print failover (FAILOVER_CHECK)
    Runout sensors now trigger live tool switching to a configured backup
    mid-print, not just at T<n> call time like _TOOL_ROUTER's existing
    logic. Also clarifies in the Tool Map legend that backup is keyed to
    the tool being called, not the tool it maps to. Confirmed working live.
    [tool_feeder_macros.cfg]
2026-08-05 Deploy prime_purge.cfg via the installer
    It was added to the repo but never wired into install_feeder() - every
    deploy so far had been a manual scp straight to a printer, so a fresh
    install never got it. Now copied alongside tool_feeder_macros.cfg (same
    copy_with_prompt pattern), with an [include prime_purge.cfg] mention added
    to the post-install next-steps output.
2026-08-05 Fix KlipperScreen version-skew bugs found installing on a second machine
    Confirmed live on both voron300 and a new machine, "Bobby", whose
    KlipperScreen build is ~110 commits older and disagrees on two APIs this
    project depends on:
    - self._screen.apiclient was renamed to restApi at some point upstream -
    voron300's build has restApi, Bobby's still has apiclient (confirmed via
    git log -S apiclient on Bobby's own KlipperScreen clone: restApi has
    never existed in its history). filament_lanes.py and tool_routing.py were
    hardcoded to restApi only, crashing every filament_lanes* panel load on
    Bobby with AttributeError.
    - SpoolmanAPI.load_all_spools()'s signature also differs: async with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
2026-08-05 Fix installer writing T{n}.cfg to the wrong config location
    Generated per-tool config files were landing flat in $CONFIG_DIR
    instead of $CONFIG_DIR/toolchanger/tools/, matching klipper-toolchanger's
    own example layout. Fixing the path also restores the existing
    backup/carry-over-real-values logic in write_generated_with_prompt,
    since it can now actually find real installs' existing tool files.
2026-09-22 Add UNASSIGN_SPOOL macro, wire both Clear buttons and runout through it
    Adds a console/macro way to clear a tool's spool assignment (Spoolman
    or manual) in one call, matching what tapping "Clear" in KlipperScreen
    already did. Both KlipperScreen Clear buttons now route through this
    same macro instead of duplicating the gcode inline — this also fixes a
    real bug where Manual Assign's Clear only ever cleared t{n}__manual,
    leaving a stale t{n}__spool_id behind if the lane had been
    Spoolman-assigned before switching to manual. The real filament runout
    sensor (not the toolhead-presence or jam sensors) now also calls
    UNASSIGN_SPOOL automatically, since a runout means the spool is
    physically empty.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
    [tool_feeder_macros.cfg]
2026-09-22 Fix Manual Entry assignments never reaching lane_sync's OrcaSlicer sync
    _tool_map_from_variables() only ever looked for t{n}__spool_id in
    save_variables, so any manually-assigned lane (filament_lanes_manual.py's
    save path, no Spoolman spool) always synced as an empty slot in
    lane_data, even though KlipperScreen's own panels displayed it
    correctly via a separate read path. Not a regression — this gap
    existed since Manual Entry was first added.
    Now also scans for t{n}__manual and fills in any tool not already
    resolved from a real spool_id, via a new _manual_to_lane() helper
    mirroring filament_lanes.py's own Spoolman-wins precedence for
    on-screen display. Also guards real spool_id assignment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
2026-09-22 Add Filament Lanes to KlipperScreen's __print menu, reachable mid-print
    KlipperScreen replaces the whole idle-screen panel history with the
    print-status page once a print starts (job_status's own show_panel
    call, stock behavior) — the __main menu entry alone is unreachable
    from that point on. KlipperScreen has a second, separate menu tree for
    this, __print, which its own built-in Spoolman panel already uses to
    stay reachable while printing. Filament Lanes now gets the same
    treatment via a second [menu __print filament_lanes] block, so
    SET_TOOLMAP/failover remapping and spool assignment stay reachable
    mid-print, not just when idle. Pure config — no macro or panel code
    changes needed.
    Co-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
2026-09-22 Stop hardcoding SPOOLMAN_URL — proxy Spoolman calls through Moonraker
    Found on Bobby: spoolman-lane-sync couldn't reach Spoolman because its
    .env's SPOOLMAN_URL still pointed at an old host, while the printer's
    own moonraker.conf had long since been repointed at the real,
    centrally-hosted instance. A separately-configured URL has no way to
    stay in sync with moonraker.conf if that ever changes again.
    Moonraker's own spoolman component already registers
    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
2026-09-23 Add .gitattributes to normalize line endings to LF
    This checkout lives on an SMB share and has been silently accumulating
    CRLF noise on every checkout (same root-cause family as the
    core.filemode false fix) — the last session found and discarded ~2000
    lines of pure line-ending diff across 10 files that had no real content
    change. * text=auto eol=lf normalizes text files to LF going forward.
    hardware/** is excluded (-text) — CAD reference files like the STEP
    export already use CRLF from their originating tool, and renormalizing
    would just produce a huge, functionally meaningless diff.
